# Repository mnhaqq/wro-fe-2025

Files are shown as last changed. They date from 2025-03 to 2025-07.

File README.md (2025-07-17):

# Lonely At The Top
This is the official repository of team LONELY AT THE TOP for the World Robot Olympiad Future Engineers category. This repository contains everything related to the development of the robot. And this README contains the official documentation of the team.

# 📜 Repository Overview

Welcome to our robotics project repository! Here's a breakdown of the contents:

- **`schemes/`**  
  Contains the circuit diagrams used in our robot.

- **`models/`**  
  Includes all the 3D printed parts of the robot that will be taken to the international competition.

- **`src/`**  
  All source code for both challenges — with and without obstacles.

- **`t-photos/`**  
  Photos of the team, including one formal shot and one funny shot.

- **`v-photos/`**  
  Photos of the robot from every angle, including previous versions.

- **`video/`**  
  Contains videos where you can see our robot in action, completing both challenges.

- **`README.md`**  
  Our complete development journey! Here we explain every aspect of building the robot — from design to implementation.

# Components
A list of all the electrical components in the robot.
<table>
  <tr>
    <td><strong>Step Down Module</strong></td>
    <td><strong>Raspberry Pi 5</strong></td>
    <td><strong>Raspberry Pi 12MP Camera Module 3</strong></td>
  </tr>
  <tr>
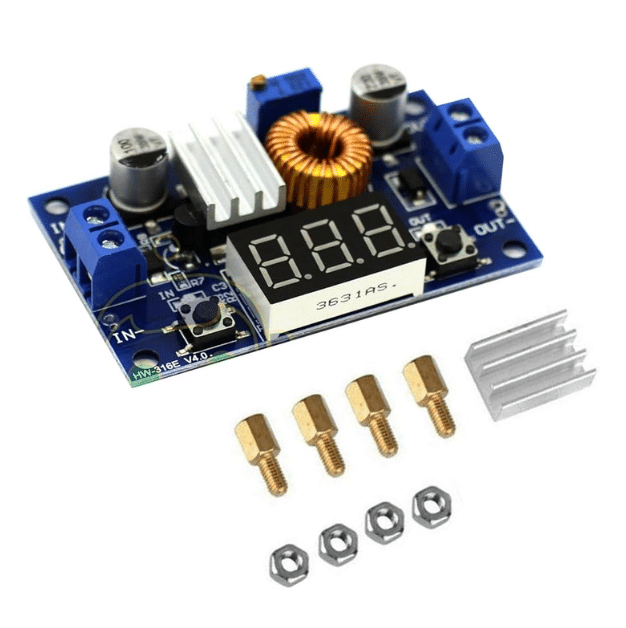
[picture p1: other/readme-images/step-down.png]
    <td></td>
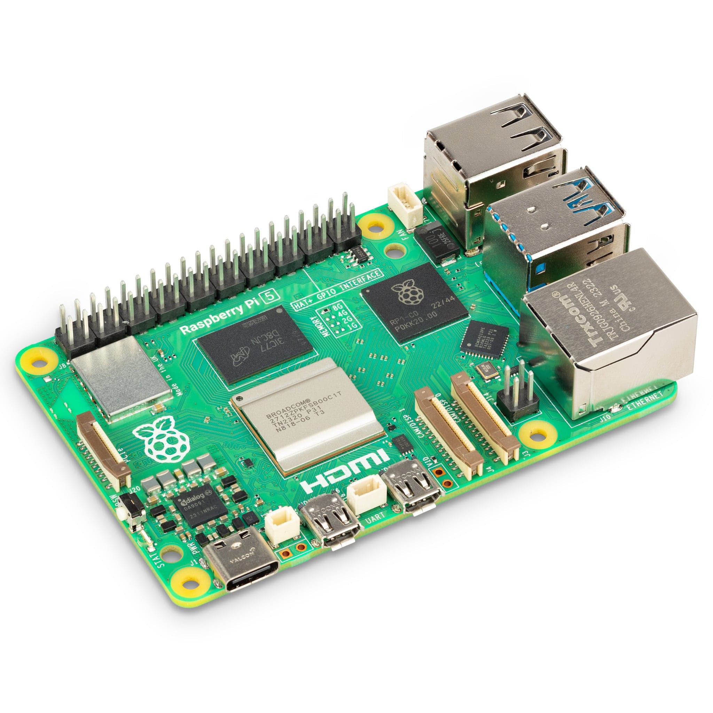
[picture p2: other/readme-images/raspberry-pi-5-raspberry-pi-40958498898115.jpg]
    <td></td>
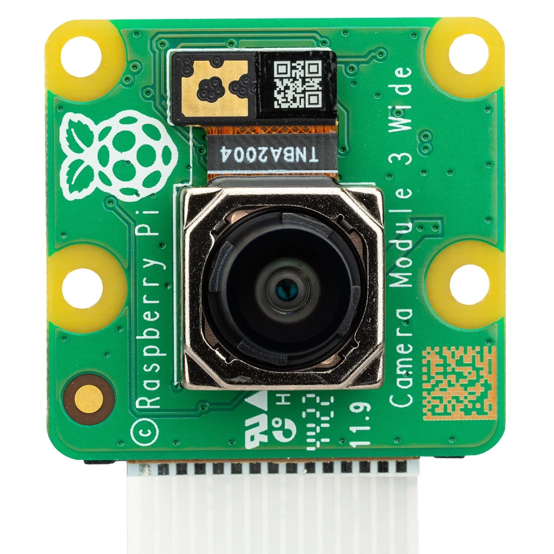
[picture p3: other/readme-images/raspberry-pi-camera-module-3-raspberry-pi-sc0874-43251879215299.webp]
    <td></td>
  </tr>
  <tr>
    <td><strong>Arduino Nano</strong></td>
    <td><strong>10k ohm resistor</strong></td>
    <td><strong>Push Button</strong></td>
  </tr>
  <tr>
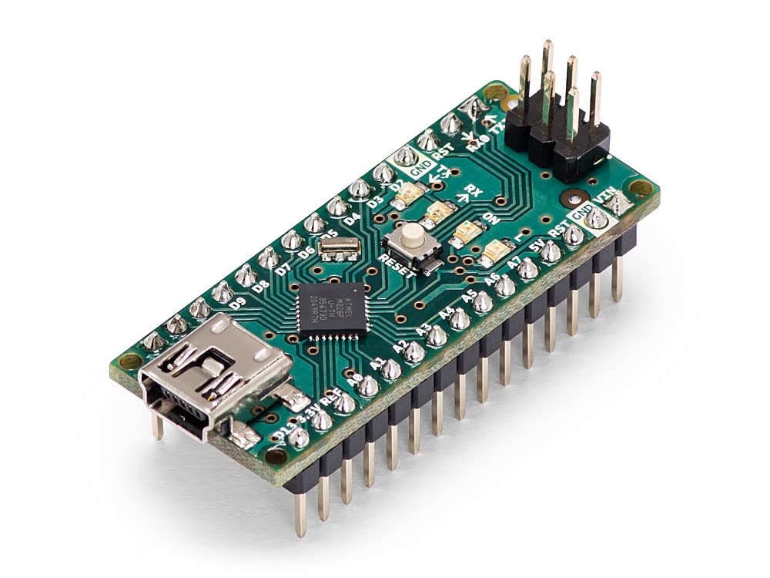
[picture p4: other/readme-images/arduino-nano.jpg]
    <td></td>
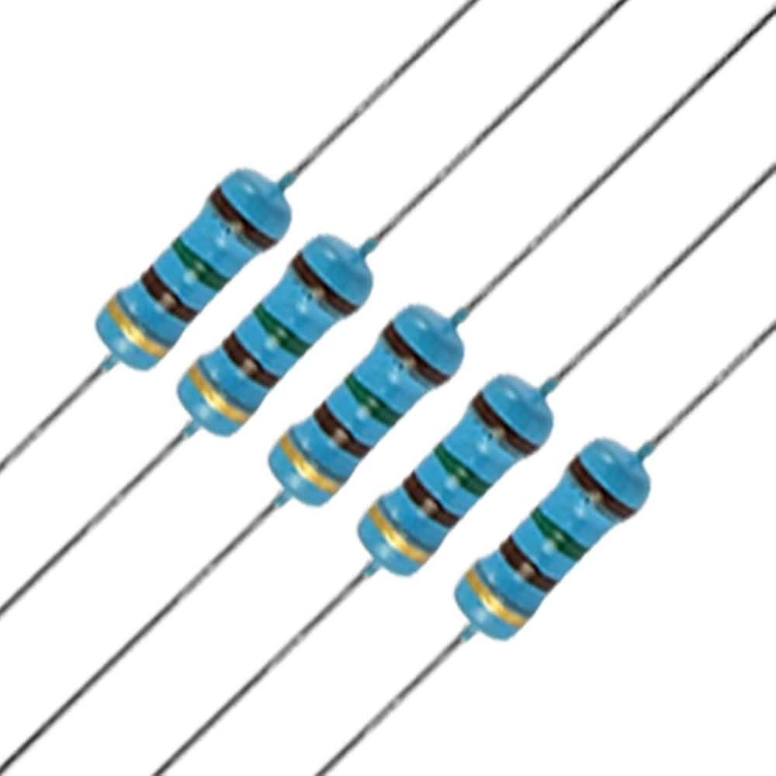
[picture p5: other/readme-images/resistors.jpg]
    <td></td>
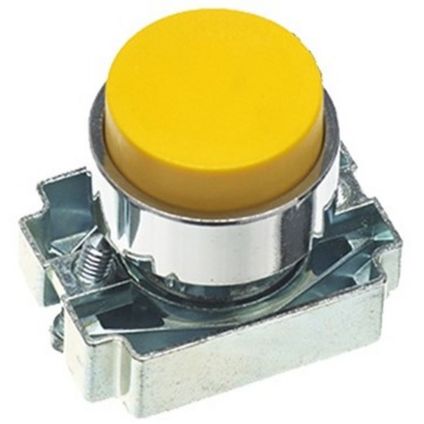
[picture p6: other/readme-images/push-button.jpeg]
    <td></td>
  </tr>
  <tr>
    <td><strong>USB cable A to USB Mini B</strong></td>
    <td><strong>4x 18650 Batteries</strong></td>
    <td><strong>Jumper Wires</strong></td>
  </tr>
  <tr>
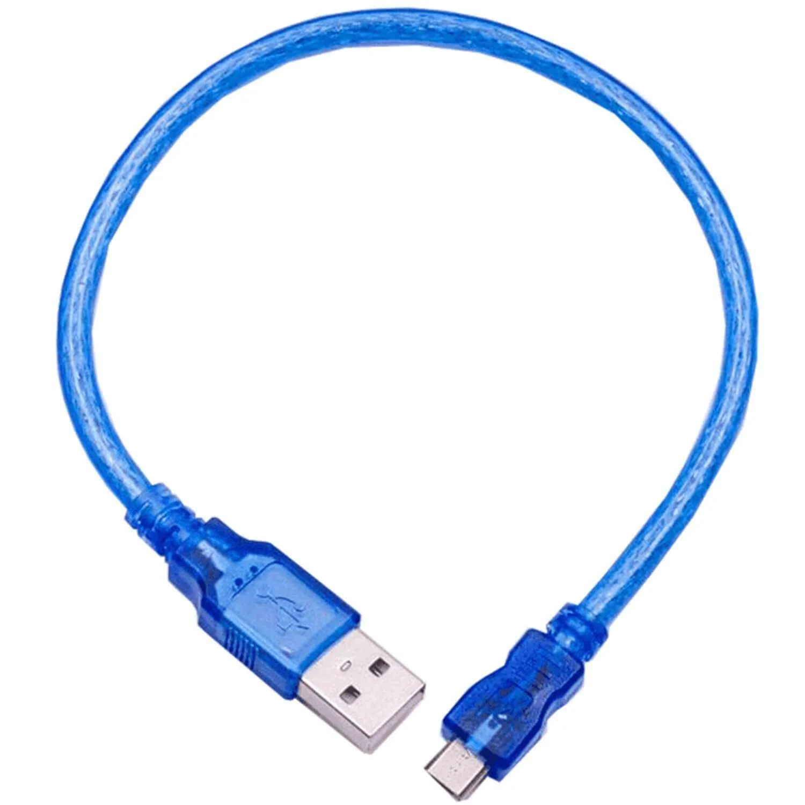
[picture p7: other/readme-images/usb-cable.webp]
    <td></td>
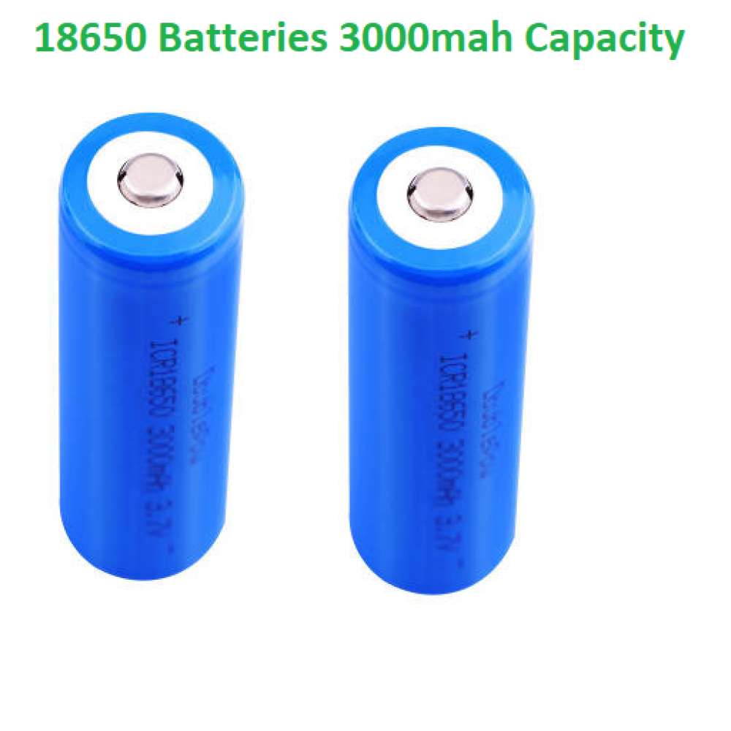
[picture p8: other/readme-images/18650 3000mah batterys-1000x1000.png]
    <td></td>
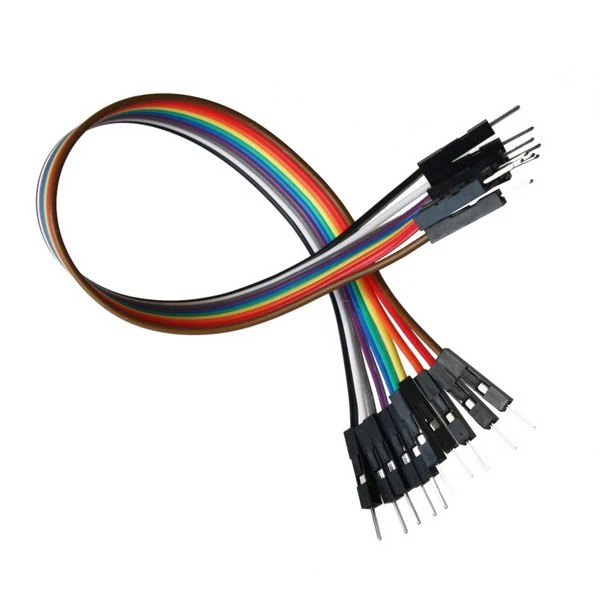
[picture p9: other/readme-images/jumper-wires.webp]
    <td></td>
  </tr>
  <tr>
    <td><strong>Raspberry Pi FPC Camera Cable</strong></td>
    <td><strong>LaTrax Rally 75054</strong></td>
    <td></td>
  </tr>
  <tr>
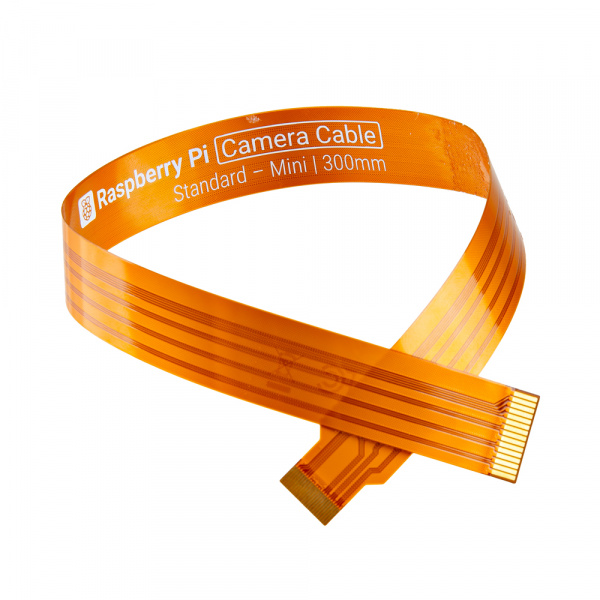
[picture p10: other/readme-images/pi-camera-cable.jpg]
    <td></td>
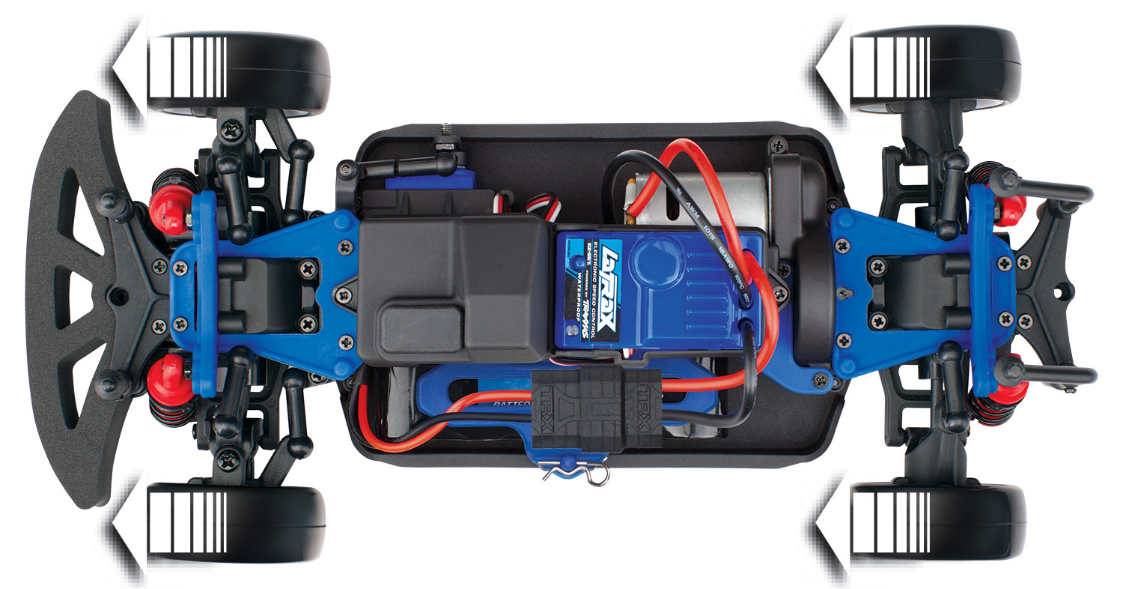
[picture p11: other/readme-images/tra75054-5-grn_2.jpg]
    <td></td>
    <td></td>
  </tr>
</table>

Below we show how we connect all these componenents
## 🧩 Use of Each Component

### 🔌 DC-DC XL4015 Adjustable Step-down Module (5A 75W with Digital Voltmeter)
This power module is used to **step down the voltage** from our 2s2p 18650 battery pack (8.4V when fully charged) to a stable **5.2V**, which is ideal for powering the **Raspberry Pi 5**.  
The built-in digital display helps us monitor the output voltage easily and adjust it precisely, ensuring the Raspberry Pi receives clean and safe power throughout operation.

---

### 🧠 Raspberry Pi 5
This serves as the **main processing unit or brain** of our robot. It handles:
- Real-time image processing from the camera module  
- Sensor data interpretation  
- Pathfinding algorithms and decision-making logic  
- Communication with the Arduino Nano  

We chose the Raspberry Pi 5 due to its powerful processor, increased RAM, and GPIO compatibility, making it perfect for compute-heavy robotics tasks.

---

### 📷 Raspberry Pi 12MP Camera Module 3
This camera captures **high-resolution images** of the game field, which are then processed by the Raspberry Pi for tasks such as:
- Line and object detection  
- Path planning  
- Visual-based decisions  

Its high quality and native Pi compatibility make it ideal for real-time computer vision applications.

---

### 🧰 Arduino Nano
The **Arduino Nano** is used as a dedicated microcontroller to:
- Interface with motor drivers  
- Control the steering servo and drive motors  
- Execute low-level, timing-critical control tasks  

This division of labor makes the control system more efficient and responsive.

---

### 📏 10kΩ Resistor
We use this as a **pull-down resistor** in our push button circuit to ensure that the GPIO pin connected to the button reads a stable LOW state when the button is not pressed, preventing **false signals**.

---

### 🔘 Push Button
A simple button used to **start or stop the robot's program**.  
It gives us manual control over the code execution without needing remote access or a keyboard.

---

### 🔋 18650 Lithium-ion Batteries (2s2p Configuration)
We wired four 18650 cells in a **2-series 2-parallel** configuration to:
- Get a nominal voltage of 7.4V (8.4V when fully charged)  
- Double the capacity and current output  

This ensures sufficient runtime and power delivery for the Raspberry Pi and motors.

---

### 🧵 Jumper Wires
Used to connect various components such as:
- Sensors to the Raspberry Pi  
- GPIO pins to the button and ultrasonic module  

They offer flexibility and are great for testing and prototyping.

---

### 🔌 USB Cable A to Mini B
This cable connects the **Raspberry Pi to the Arduino Nano**, enabling:
- Power supply to the Arduino  
- Serial communication for sending control commands  

Essential for integrating the two microcontrollers.

---

### 🚗 LaTrax Rally 75054 Chassis
This is a **commercial RC car chassis** we used as the robot's base. It provides:
- A strong and stable platform  
- Built-in drivetrain and suspension  
- Easy mounting for electronics and sensors  

It reduced the time spent on mechanical design and improved mobility and reliability.

---

### 🎥 Raspberry Pi FPC Camera Cable (Standard-Mini)
This flexible flat ribbon cable connects the **Camera Module 3** to the Raspberry Pi.  
The mini connector fits perfectly with our camera, and the cable length allows us to position the camera optimally for capturing the game field.

---

# Circuit Diagram
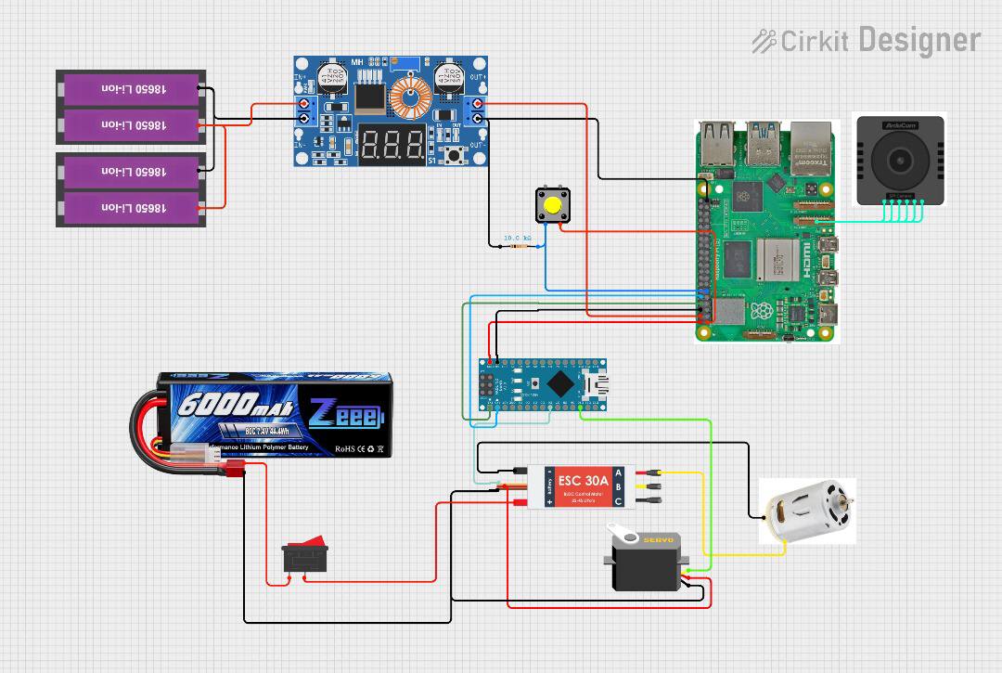
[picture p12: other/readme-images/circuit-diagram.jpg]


This circuit diagram represents the core electronic system of our robot, powered by two distinct battery packs and controlled using both an **Arduino Nano** and a **Raspberry Pi 5**. Each component is strategically connected to fulfill its specific function in the robot's operation.

### ⚙️ Power Supply and Regulation

- The system uses two battery packs:
  - A **2S2P 18650 Li-ion battery pack** to power the Raspberry Pi through a **DC-DC XL4015 step-down converter**, which regulates the voltage from 8.4V down to 5.2V to ensure safe operation of the Pi.
  - A **6000mAh 7.4V LiPo battery** is dedicated to powering the **DC motor** via an **ESC (Electronic Speed Controller)**, providing the high current required for reliable movement and acceleration.

### 🧠 Microcontroller & Microprocessor

- The **Raspberry Pi 5** serves as the central processing unit of the robot. It:
  - Processes data from the **Raspberry Pi Camera Module**
  - Sends movement instructions to the **Arduino Nano**
  - Interfaces with input components like the **push button** through GPIO pins

- The **Arduino Nano** is responsible for:
  - Receiving control commands from the Raspberry Pi
  - Driving the **servo motor** for steering
  - Sending PWM signals to the **ESC** to control the DC motor
  - Handling low-level real-time tasks for precise control

### 📷 Camera Integration

A **12MP Camera Module 3** is connected to the Raspberry Pi using a **FPC ribbon cable**. This camera captures visual data from the field for image processing tasks such as:
- Line tracking
- Object detection
- Lane following and obstacle avoidance

This enables the robot to make autonomous navigation decisions based on what it "sees."

### 🔁 Actuation

- A **DC motor**, connected through an **ESC**, provides torque and speed for forward and backward movement.
- A **servo motor** controls the steering mechanism of the chassis, allowing the robot to make turns with precision.

### 🎮 Input and Control

- A **push button** is connected to the Raspberry Pi via GPIO pins and a **10kΩ resistor** (as a pull-down resistor) to prevent floating values. This button is used to **start or stop** the program execution manually.
- **Jumper wires (UTP)** are used to make precise connections between components like the sensors, Arduino, and Raspberry Pi, ensuring signal integrity and clean communication.

---

### ✅ Summary

This modular design ensures:
- **Separation of logic and power domains**, preventing electrical noise or surges from affecting control logic
- **Efficient power delivery** to both the Raspberry Pi and motors
- **Clear division of responsibilities** between the Raspberry Pi (for high-level processing) and Arduino (for motor control)
- **Scalability**, allowing us to easily modify or extend the system for future challenges

The diagram illustrates a robust and well-integrated control system suitable for real-world robotic competitions, ensuring stability, performance, and flexibility in operation.

# 3D Parts
| Part | Description |
|---|---|
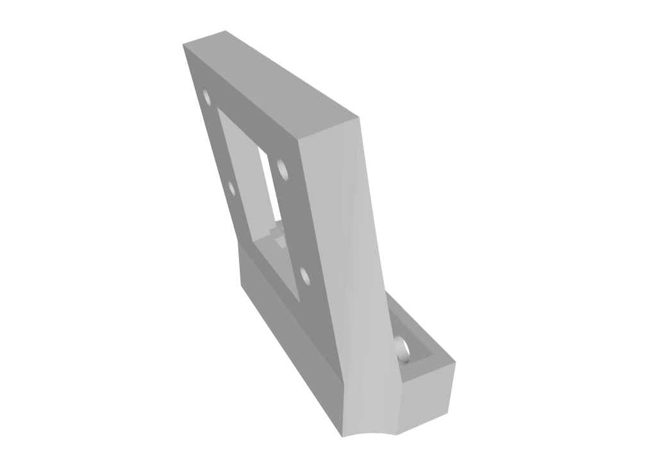
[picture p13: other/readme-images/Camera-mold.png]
|  | This 3D-printed component serves as a protective and structural housing for the camera, referred to as the camera mold. It is angled at approximately 170 degrees to optimize the camera's field of view, enabling better visibility of the game field during operation. |
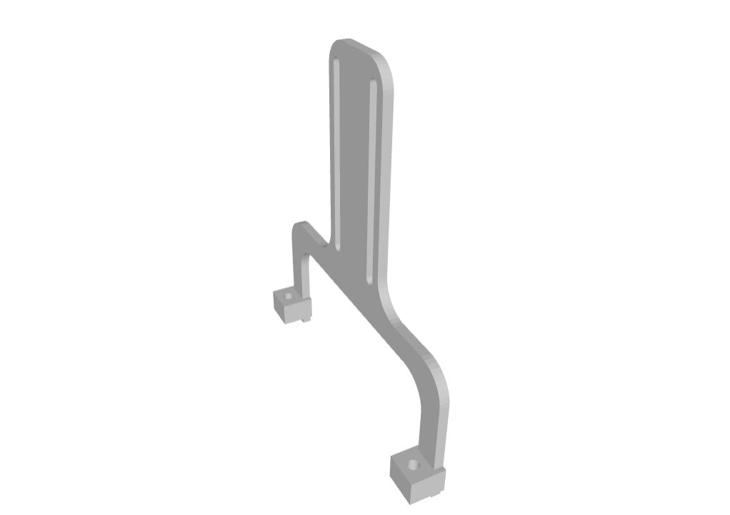
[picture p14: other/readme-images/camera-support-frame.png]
|  | This is the camera support frame, designed to pair with the camera mold to ensure stable and accurate camera positioning. Its adjustable height mechanism allows fine-tuning of the camera's elevation to achieve the desired field of view, enhancing visibility of the game field. |
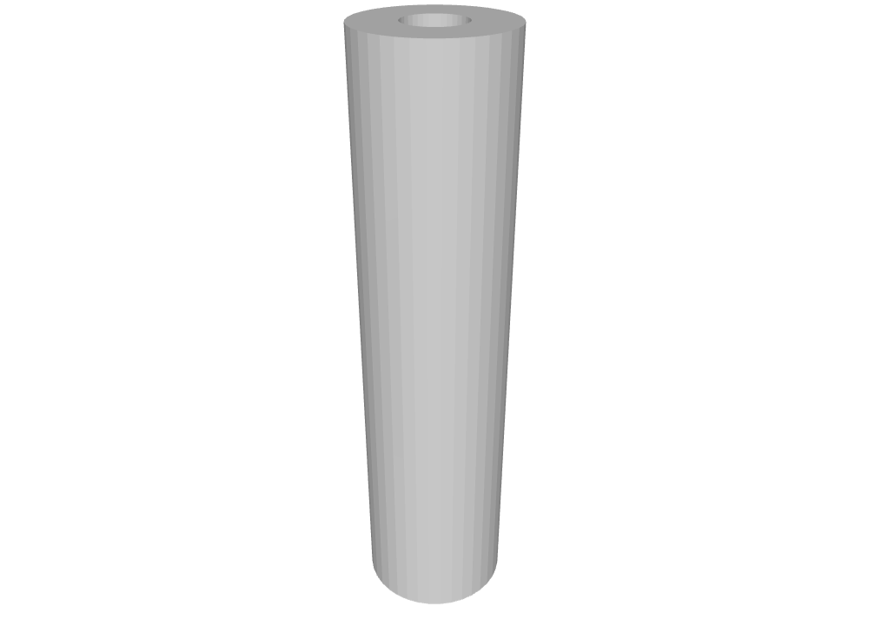
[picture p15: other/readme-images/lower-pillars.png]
|  | These pillars serve as the structural supports for the robot, holding up each deck and ensuring overall stability. Designed to bear the weight of the stacked components, the eight pillars also provide connection points that keep the entire robot assembly securely integrated |
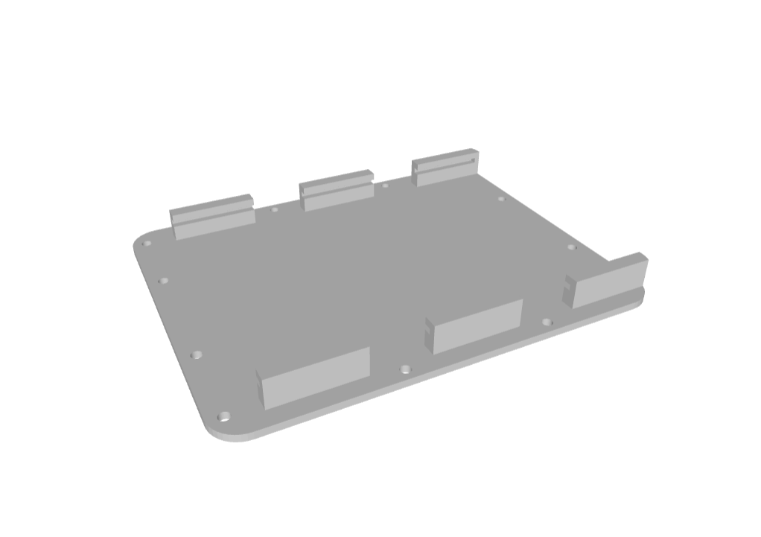
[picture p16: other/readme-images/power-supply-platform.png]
|  | This is the second deck (counting from the top), designed to hold the step-down power module and the batteries that supply power to the Raspberry Pi 5. It provides a stable platform for power distribution components and ensures efficient use of vertical space in the robot’s design. |
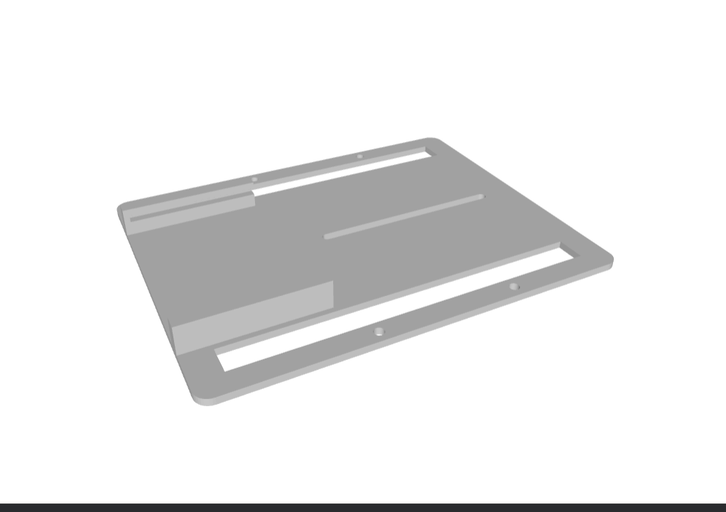
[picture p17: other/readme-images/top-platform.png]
|  | This is the first deck (topmost level), which houses the Raspberry Pi 5, Arduino Nano, and a control button. It also interfaces with the camera support frame, featuring a sliding mechanism that allows the frame to be adjusted forward or backward as needed to optimize the camera’s positioning. |
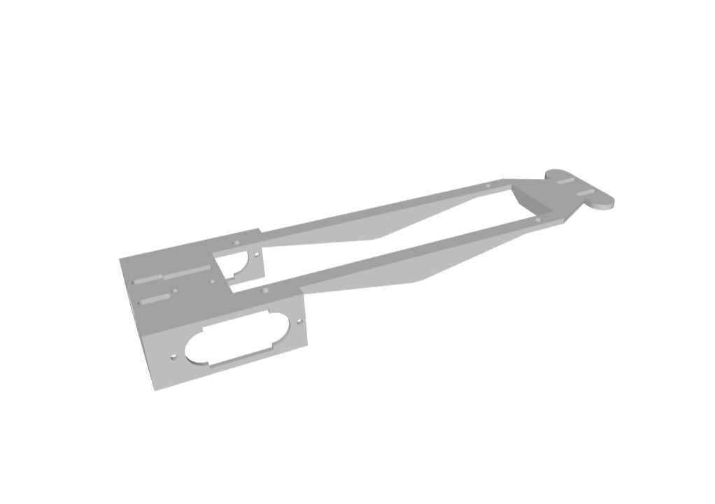
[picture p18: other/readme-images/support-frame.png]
|  | Serve as the foundation for the robot's structure. Provides support for all other printed components and form the critical connection between the RC chassis and the custom 3D-printed assemblies, ensuring a stable and integrated build.  |
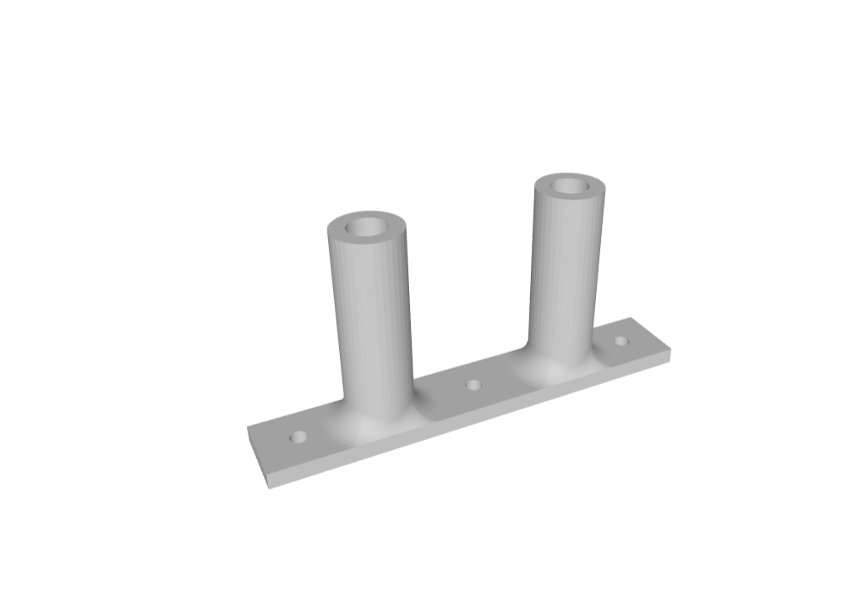
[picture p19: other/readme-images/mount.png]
|  | Combined with the support frame above to perform it's function. There's two of this part |

# Code and Programming Overview

The codebase is divided into two main components, each located in separate folders:

## PiArduinoInterface

This folder contains the Arduino code responsible for low-level control of the vehicle. It manages the **steering servo** and **driving motor**, and receives commands from the Raspberry Pi over a serial interface.

### File Overview

#### `PiArduinoInterface.ino`
The main entry point of the Arduino program:
- Sets up serial communication and initializes hardware components (servos and motors).
- Continuously reads and parses commands sent from the Raspberry Pi.
- Executes commands such as setting motor speed or adjusting servo angles.
- Includes an **auto-stop safety feature** that stops the motor if no command is received within a set interval.

#### `commands.h`
Defines the set of valid single-character serial commands used by the Raspberry Pi to control the Arduino:
- Examples include:  
  - `'s'` – Set servo position  
  - `'m'` – Set motor speed  
  - `'d'` – Digital read  
  - `'a'` – Analog read  

These commands are parsed and executed in `PiArduinoInterface.ino`.

#### `servos.h`
Declares the `SweepServo` class and configuration settings for the servos:
- Controls how fast the servo sweeps to its target position.
- Stores pin assignments and initial angles.
- Declares a global array `servos[]` for managing multiple servos.

#### `servos.ino`
Implements the `SweepServo` class:
- Smoothly moves a servo to a target position one degree at a time.
- Supports adjustable speed via a delay between steps.
- Useful for precise or slow movements, such as robotic arms or steering mechanisms.

#### `motor_driver.h`
Contains motor control settings:
- Specifies the motor control pin (default: pin 3) used for the ESC (Electronic Speed Controller).
- Declares functions for initializing the motor and setting its speed.

#### `motor_driver.ino`
Implements the motor driver functions:
- Uses the `Servo` library to control an ESC-based brushed or brushless motor.
- Supports setting motor speed via PWM signals.
- Provides an `initMotorController()` function to safely initialize the ESC.

---

# MainCode
---
This folder contains the main logic and it controls the arduino which in turn controls motors

## `start.py` — Script Launcher via Physical Button

This script enables hardware-based control of another Python script (`open.py`) using a physical push button connected to a Raspberry Pi's GPIO pin. Pressing the button starts the `open.py` script, and pressing it again stops the script.

---

### Features

* Uses GPIO interrupts to detect button press.
* Launches `open.py` or `obstacle` using `subprocess.Popen`.
* Pressing the button again terminates the script gracefully.
* Cleanly shuts down on keyboard interrupt (`Ctrl+C`).

---

### Code Breakdown

```python
import RPi.GPIO as GPIO
import subprocess
import time
import os
import signal
```

Imports all necessary libraries:

* `RPi.GPIO` for interacting with GPIO pins.
* `subprocess` for running external scripts.
* `os` and `signal` for process control.

---

```python
BUTTON_PIN = 17
GPIO.setmode(GPIO.BCM)
GPIO.setup(BUTTON_PIN, GPIO.IN, pull_up_down=GPIO.PUD_DOWN)
```

* Sets **GPIO17** as input.
* Configures it with a **pull-down resistor** to detect rising edges (button press).

---

```python
process = None
```

* Stores a reference to the running process so it can be terminated later.

---

```python
def toggle_executable(channel):
    global process
    if process is None:
        print("Button pressed! Starting script...")
        process = subprocess.Popen(
            ['python3', 'open.py'],
            cwd='/home/pi/Documents/wro-fe-2025/src/MainCode/'
        )
    else:
        print("Button pressed! Stopping script...")
        try:
            os.kill(process.pid, signal.SIGTERM)
        except Exception as e:
            print(f"Error stopping script: {e}")
        process = None
```

This **callback function** is triggered when the button is pressed:

* If no script is running, it launches `open.py`.
* If a script is already running, it stops it using `SIGTERM`.

---

```python
GPIO.add_event_detect(BUTTON_PIN, GPIO.RISING, callback=toggle_executable, bouncetime=300)
```

Registers an **interrupt** on the button pin for **rising edge detection**.

* `bouncetime=300` helps to debounce the button (ignores multiple presses within 300ms).

---

```python
try:
    print("Waiting for button press to toggle script...")
    while True:
        time.sleep(0.1)
except KeyboardInterrupt:
    pass
finally:
    GPIO.cleanup()
    if process:
        os.kill(process.pid, signal.SIGTERM)
```

Main loop waits for button events.

* Gracefully cleans up GPIO and stops the running process on `Ctrl+C`.

---

## `ArduinoComms.py` — Arduino Serial Communication Handler

This module provides a Python class for communicating with an Arduino over a serial connection using the `pyserial` library. It supports sending drive and steering commands, as well as handling connection setup, teardown, and message formatting.

---

### Features

* Connect to an Arduino over a serial port.
* Automatically validates and converts baud rates.
* Send and receive messages over serial.
* Built-in functions to control drive and steering motor values.

---

### Code Breakdown

#### Baud Rate Validation

```python
def convert_baud_rate(baud_rate):
    supported_baud_rates = [
        1200, 1800, 2400, 4800, 9600,
        19200, 38400, 57600, 115200, 230400
    ]
    if baud_rate in supported_baud_rates:
        return baud_rate
    else:
        print(f"Error! Baud rate {baud_rate} not supported! Defaulting to 57600")
        return 57600
```

* Ensures only supported baud rates are used.
* Falls back to a default value of **57600** if an unsupported rate is provided.

---

### `ArduinoComms` Class

#### Connect to Arduino

```python
comms = ArduinoComms()
comms.connect(serial_device='/dev/ttyUSB0', baud_rate=57600, timeout_ms=1000)
```

* `serial_device`: Serial port connected to the Arduino (e.g. `/dev/ttyUSB0` on Linux, `COM3` on Windows).
* `baud_rate`: Must be one of the supported baud rates.
* `timeout_ms`: Timeout for reading serial data, in milliseconds.

---

#### Disconnect

```python
comms.disconnect()
```

* Closes the serial connection if it's open.

---

#### Check Connection Status

```python
if comms.connected():
    print("Arduino is connected.")
```

* Returns `True` if the serial port is open.

---

#### Send Messages

```python
response = comms.send_msg("ping\r", print_output=True)
```

* Sends a message string (terminated by `\r`).
* Optionally prints both the sent and received message.
* Returns the decoded response string.

---

#### Send Empty Message

```python
comms.send_empty_msg()
```

* Sends an empty carriage return to "ping" the Arduino or reset the line.

---

#### Set Drive Motor Value

```python
comms.set_drive_motor_value(100)
```

* Sends a command in the format: `o <value>\r`
* Used to control the drive motor speed.

---

#### Set Steering Motor Value

```python
comms.set_steering_motor_value(-30)
```

* Sends a command in the format: `s 0 <value>\r`
* Used to control steering angle or direction.

---

### Example Usage

```python
from ArduinoComms import ArduinoComms

comms = ArduinoComms()
comms.connect('/dev/ttyUSB0', 57600, 1000)

if comms.connected():
    comms.set_drive_motor_value(150)
    comms.set_steering_motor_value(-20)

comms.disconnect()
```

---

## `KeyboardControl.py` — Keyboard Interface for Arduino Motor Control

This script allows manual control of a robot’s drive and steering motors via keyboard input. It uses the `keyboard` library to detect key presses and sends commands to an Arduino over serial using the `ArduinoComms` class.

---

### Features

* Incrementally adjusts **speed** and **steering angle** based on keys pressed.
* Supports continuous key press detection with a debounce delay.
* Safe stop and reset on spacebar press.
* Graceful exit on pressing `q`.
* Automatic connection to Arduino serial port.

---

### Code Breakdown

#### Setup and Initialization

```python
class KeyboardController:
    def __init__(self):
        self.arduino = ArduinoComms()
        self.speed = 0
        self.steer = 90  # Neutral steering position
        self.last_action_time = time.time()
```

* Instantiates `ArduinoComms` for serial communication.
* Initializes speed and steering values.
* Tracks time of last input to limit update frequency.

---

#### Arduino Connection Setup

```python
def arduino_setup(self):
    try:
        self.arduino.connect('/dev/serial/by-id/usb-1a86_USB2.0-Ser_-if00-port0', 9600, 1000)
        if self.arduino.connected():
            print("Connected to Arduino.")
        else:
            print("Failed to connect.")
    except Exception as e:
        print(f"Error: {e}")
```

* Connects to Arduino at the specified serial port and baud rate.
* Handles exceptions and reports connection status.

---

#### Speed and Steering Controls

```python
def set_speed(self, direction):
    if direction:
        self.speed += 10
    else:
        self.speed -= 10
    self.speed = max(min(self.speed, 500), -500)
    if self.arduino.connected():
        self.arduino.set_drive_motor_value(self.speed)
```

* Adjusts speed by ±10 units per key press.
* Limits speed between -500 and 500.
* Sends updated speed to Arduino.

```python
def set_steer(self, direction):
    if direction:
        self.steer += 5
    else:
        self.steer -= 5
    self.steer = max(min(self.steer, 135), 45)
    if self.arduino.connected():
        self.arduino.set_steering_motor_value(self.steer)
```

* Adjusts steering angle by ±5 degrees per key press.
* Limits steering between 45 and 135 degrees.
* Sends updated steering value to Arduino.

---

#### Stop and Reset

```python
def stop(self):
    self.speed = 0
    self.steer = 90
    if self.arduino.connected():
        self.arduino.set_steering_motor_value(self.steer)
        self.arduino.set_drive_motor_value(self.speed)
```

* Resets speed to 0 and steering to neutral position.
* Sends stop commands to Arduino.

---

#### Main Control Loop

```python
def run(self):
    self.arduino_setup()
    try:
        while True:
            now = time.time()
            if now - self.last_action_time > 0.1:  # Debounce 100ms
                if keyboard.is_pressed('w'):
                    self.set_speed(True)
                if keyboard.is_pressed('s'):
                    self.set_speed(False)
                if keyboard.is_pressed('a'):
                    self.set_steer(True)
                if keyboard.is_pressed('d'):
                    self.set_steer(False)
                if keyboard.is_pressed('space'):
                    self.stop()
                self.last_action_time = now

            if keyboard.is_pressed('q'):
                break

            time.sleep(0.01)
    finally:
        if self.arduino.connected():
            self.arduino.disconnect()
```

* Reads keyboard input continuously.
* Updates speed and steering every 100 ms on key press.
* Stops and resets on spacebar.
* Exits on `q` and safely disconnects Arduino.

---

### Usage

Run the script with Python 3 in an environment with `keyboard` and your `ArduinoComms.py` available:

```bash
python3 keyboard_controller.py
```

Controls:

| Key | Action |
| --- | --- |
| `w` | Increase speed |
| `s` | Decrease speed |
| `a` | Steer left (increase angle)  |
| `d` | Steer right (decrease angle) |
| `space` | Stop and reset |
| `q` | Quit program |

---

###  Notes

* The script requires root or admin privileges on some OSes for `keyboard` library to detect key presses.
* Update the serial port path in `arduino_setup()` to match your system’s Arduino device.

---

## `pid.py` — PID Control Algorithm Implementation

This module implements a simple Proportional-Integral-Derivative (PID) controller class for feedback control systems, commonly used in robotics and automation.

---

### Code Breakdown

#### PID Controller Class

```python
class PIDController:
    def __init__(self, kp, ki, kd):
        self.kp = kp          # Proportional gain
        self.ki = ki          # Integral gain
        self.kd = kd          # Derivative gain
        self.prev_error = 0   # Error from previous step (for derivative term)
        self.integral = 0     # Accumulated error (for integral term)

    def compute(self, error):
        self.integral += error
        derivative = error - self.prev_error
        output = (self.kp * error) + (self.ki * self.integral) + (self.kd * derivative)
        self.prev_error = error
        return output
```

---

### Features

* Calculates the PID output given a current error value.
* Maintains internal state for integral and derivative computations.
* Simple interface: instantiate with gains and call `compute(error)` on each control cycle.

---

### Usage Example

```python
pid = PIDController(kp=1.2, ki=0.01, kd=0.05)

while True:
    error = desired_value - measured_value
    control_signal = pid.compute(error)
    # Use control_signal to drive actuators
```

---

### ⚙️ Notes

* Make sure to call `compute` regularly with the latest error measurement.
* Gains (`kp`, `ki`, `kd`) should be tuned for your specific system for stable control.

---

## `utils.py` — Image Processing for Color-Based Object Detection

This module provides utility functions to detect colored objects in specific Regions of Interest (ROIs) within images, using OpenCV and LAB color space thresholds.

---

### Functions Overview

---

#### `display_roi(img, ROIs, color)`

Draws bounding boxes around specified ROIs on the given image.

```python
def display_roi(img, ROIs, color):
    for ROI in ROIs: 
        img = cv2.line(img, (ROI[0], ROI[1]), (ROI[2], ROI[1]), color, 4)
        img = cv2.line(img, (ROI[0], ROI[1]), (ROI[0], ROI[3]), color, 4)
        img = cv2.line(img, (ROI[2], ROI[3]), (ROI[2], ROI[1]), color, 4)
        img = cv2.line(img, (ROI[2], ROI[3]), (ROI[0], ROI[3]), color, 4)
    
    return img
```

* **Parameters:**

  * `img` — The image to draw on.
  * `ROIs` — List of tuples defining rectangular regions `(x1, y1, x2, y2)`.
  * `color` — Color for the ROI lines (BGR tuple).
* **Returns:** Image with ROI rectangles drawn.

---

#### `find_contours(img_lab, lab_range, ROI)`

Segments the LAB image within a ROI using color thresholds, applies morphological operations, and finds contours of the detected regions.

```python
def find_contours(img_lab, lab_range, ROI):
    img_segmented = img_lab[ROI[1]:ROI[3], ROI[0]:ROI[2]]
    lower_mask = np.array(lab_range[0])
    upper_mask = np.array(lab_range[1])
    mask = cv2.inRange(img_segmented, lower_mask, upper_mask)
    kernel = np.ones((5, 5), np.uint8)
    eMask = cv2.erode(mask, kernel, iterations=1)
    dMask = cv2.dilate(eMask, kernel, iterations=1)
    contours = cv2.findContours(dMask, cv2.RETR_EXTERNAL, cv2.CHAIN_APPROX_SIMPLE)[-2]
    return contours
```

* **Parameters:**

  * `img_lab` — LAB color space image.
  * `lab_range` — Tuple of lower and upper LAB thresholds.
  * `ROI` — Region of interest as `(x1, y1, x2, y2)`.
* **Returns:** List of contours found in the segmented ROI.

---

#### `max_contour(contours, ROI)`

Finds the largest contour by area that exceeds a minimum size threshold and returns its properties.

```python
def max_contour(contours, ROI): 
    maxArea = 0
    maxY = 0
    maxX = 0
    mCnt = 0
    
    for cnt in contours:
        area = cv2.contourArea(cnt)
        if area > 100: 
            approx = cv2.approxPolyDP(cnt, 0.01*cv2.arcLength(cnt,True), True)
            x,y,w,h = cv2.boundingRect(approx)
            x += ROI[0] + w // 2
            y += ROI[1] + h
            if area > maxArea:
                maxArea = area
                maxY = y
                maxX = x
                mCnt = cnt
    return [maxArea, maxX, maxY, mCnt]
```

* **Parameters:**

  * `contours` — List of contours.
  * `ROI` — Region of interest as `(x1, y1, x2, y2)`.
* **Returns:** List `[maxArea, maxX, maxY, maxContour]` representing the largest contour’s area, centroid X, centroid Y, and contour points.

---

#### `display_variables(variables)`

Prints multiple variable name-value pairs in the terminal and overwrites the previous output for real-time updates.

```python
def display_variables(variables):
    names = list(variables.keys())
    for i in range(len(names)):
        name = names[i]
        value = variables[name]
        print(f"{name}: {value}", end="\r\n")
    print("\033[F" * len(names), end="")
```

* **Parameters:**

  * `variables` — Dictionary of `{variable_name: value}` pairs.
* **Purpose:** Useful for real-time CLI display of tracking or sensor variables.

---

#### `pOverlap(img_lab, ROI, add=False)`

Detects contours of overlapping black and magenta regions within the ROI using LAB thresholding and optional mask combination.

```python
def pOverlap(img_lab, ROI, add=False):
    lower_mask = np.array(rBlack[0])
    upper_mask = np.array(rBlack[1])
    mask = cv2.inRange(img_lab[ROI[1]:ROI[3], ROI[0]:ROI[2]], lower_mask, upper_mask)

    lower_mask2 = np.array(rMagenta[0])
    upper_mask2 = np.array(rMagenta[1])
    mask2 = cv2.inRange(img_lab[ROI[1]:ROI[3], ROI[0]:ROI[2]], lower_mask2, upper_mask2)

    if not add: 
        mask = cv2.subtract(mask, cv2.bitwise_and(mask, mask2))
    else:
        mask = cv2.add(mask, mask2)

    kernel = np.ones((5, 5), np.uint8)
    eMask = cv2.erode(mask, kernel, iterations=1)
    contours = cv2.findContours(eMask, cv2.RETR_EXTERNAL, cv2.CHAIN_APPROX_SIMPLE)[-2]
    return contours
```

* **Parameters:**

  * `img_lab` — LAB color space image.
  * `ROI` — Region of interest.
  * `add` — If True, adds masks; if False, subtracts overlapping parts.
* **Returns:** List of contours found in combined masks.

---

# `open.py` - Autonomous Driving with Picamera2 and Arduino

This script implements an autonomous line following and turning system using the Raspberry Pi camera (Picamera2), Arduino motor control, and PID steering adjustments based on color detection.

---

## Overview

The program captures images from the PiCamera2, processes them in the LAB color space to detect colored regions in predefined Regions of Interest (ROIs), and computes steering angles using a PID controller. It drives motors through an Arduino based on detected path lines and turn signals.

---

## Key Features

* **PiCamera2 Setup:** Automatically selects suitable sensor modes and configures the camera.
* **Color Segmentation:** Uses LAB thresholds to detect black lines (path) and orange/blue markers (turn signals).
* **PID Steering Control:** Smooth steering adjustment based on difference in detected left and right line areas.
* **Turn Detection:** Detects turns and applies angle constraints with cooldowns to avoid repeated turn counting.
* **Arduino Communication:** Controls drive motor speed and steering angle via serial commands.
* **Debug Mode:** Visualizes ROIs, contours, and prints variable states in real-time.

---

## Usage

1. Connect the Raspberry Pi camera and Arduino controller.
2. Confirm the Arduino serial port in the script (`/dev/serial/by-id/usb-1a86_USB2.0-Ser_-if00-port0`).
3. Run the script:

```bash
python open.py
```

4. Press `q` during debug mode to quit the program.

---

## Code Snippets

### PiCamera2 Initialization and Configuration

```python
picam2 = Picamera2()
sensor_modes = picam2.sensor_modes
selected_mode = None
for mode in sensor_modes:
    if mode['size'] in [(2304, 1296), (1920, 1080), (1280, 720)]:
        selected_mode = mode
        break
if selected_mode is None:
    selected_mode = sensor_modes[0]

config = picam2.create_preview_configuration(
    main={"format": "RGB888", "size": (1280, 720)},
    sensor={"output_size": selected_mode['size'], "bit_depth": selected_mode['bit_depth']}
)

picam2.configure(config)
picam2.start()
time.sleep(1)
```

---

### Defining Regions of Interest (ROIs)

```python
# Left, Right, and Center ROIs for line and turn detection
ROI1 = [10, 420, 200, 500]    # Left
ROI2 = [1080, 420, 1270, 500] # Right
ROI3 = [540, 420, 740, 500]   # Center
```

---

### PID Controller Usage for Steering

```python
pid = PIDController(kp=0.001, ki=0, kd=0.0009)
error = rightArea - leftArea
angle = int(max(90 + pid.compute(error), 0))
```

---

### Detecting Turns and Adjusting Steering

```python
if leftArea <= turnThresh and not rTurn:
    lTurn = True
elif rightArea <= turnThresh and not lTurn:
    rTurn = True

if lTurn:
    angle = min(max(angle, sharpLeft), maxLeft)
elif rTurn:
    angle = max(min(angle, sharpRight), maxRight)
```

---

### Sending Commands to Arduino

```python
arduino.set_drive_motor_value(speed)
arduino.set_steering_motor_value(angle)
```

---

### Debug Visualization and Variables Display

```python
img = display_roi(img, [ROI1, ROI2, ROI3], (255, 204, 0))
cv2.imshow("finalColor", img)

variables = {
    "left wall area": leftArea,
    "right wall area": rightArea,
    "left turn": lTurn,
    "right turn": rTurn,
    "# turns": t,
    "lDetected": lDetected
}

display_variables(variables)

if cv2.waitKey(1) == ord('q'):
    arduino.set_drive_motor_value(0)
    break
```

---

## Parameters to Tune

* `kp`, `kd`: PID controller gains for proportional and derivative control.
* `speed`: Motor speed value.
* `turnThresh`: Threshold for detecting turn conditions.
* `exitThresh`: Threshold for detecting turn completion.
* `turn_cooldown`: Time delay to avoid counting turns multiple times.

---

# `obstacle.py` - Autonomous Lane Following and Obstacle Avoidance with PiCamera2 and Arduino

This Python script enables autonomous navigation using the Raspberry Pi Camera (Picamera2) and an Arduino for motor control. It detects colored markers and lines on the floor to steer a robot along a track, including turn detection and pillar avoidance.

---

## Features

* Captures real-time images with Picamera2.
* Detects black path lines and colored turn signals (orange, blue).
* Detects red and green pillars to trigger specific turn maneuvers.
* Uses a PID controller for smooth steering adjustments.
* Sends speed and steering commands to Arduino via serial.
* Visual debug mode with real-time contour visualization and variable display.
* Turn counting with cooldown to avoid repeated triggers.

---

## Setup Highlights

### Camera Initialization and Configuration

```python
picam2 = Picamera2()
sensor_modes = picam2.sensor_modes
selected_mode = None
for mode in sensor_modes:
    if mode['size'] in [(2304, 1296), (1920, 1080), (1280, 720)]:
        selected_mode = mode
        break
if selected_mode is None:
    selected_mode = sensor_modes[0]

config = picam2.create_preview_configuration(
    main={"format": "RGB888", "size": (1280, 720)},
    sensor={"output_size": selected_mode['size'], "bit_depth": selected_mode['bit_depth']}
)

picam2.configure(config)
picam2.start()
time.sleep(1)
```

---

### Defining Regions of Interest (ROIs) for Color Detection

```python
ROI1 = [10, 420, 200, 500]       # Left line detection region
ROI2 = [1080, 420, 1270, 500]    # Right line detection region
ROI3 = [540, 420, 740, 500]      # Center region for turn signals (orange/blue)
ROI_PILLAR = [340, 200, 940, 500] # Pillar detection region (red/green)
```

---

### PID Controller Setup for Steering

```python
kp = 0.004
kd = 0.0009
pid = PIDController(kp, 0, kd)
straightConst = 90  # Neutral steering angle
```

---

### Color Contour Detection and Steering Logic

```python
# Convert captured image to LAB color space and blur
img_lab = cv2.cvtColor(img, cv2.COLOR_BGR2Lab)
img_lab = cv2.GaussianBlur(img_lab, (7, 7), 0)

# Find contours for line and turn signal colors
cListLeft = find_contours(img_lab, rBlack, ROI1)
cListRight = find_contours(img_lab, rBlack, ROI2)
cListOrange = find_contours(img_lab, rOrange, ROI3)
cListBlue = find_contours(img_lab, rBlue, ROI3)

# Calculate max contour areas for decision making
leftArea = max_contour(cListLeft, ROI1)[0]
rightArea = max_contour(cListRight, ROI2)[0]

if max_contour(cListOrange, ROI3)[0] > 100:
    turnDir = "right"
elif max_contour(cListBlue, ROI3)[0] > 100:
    turnDir = "left"
```

---

### Detecting Pillars and Executing Turn Maneuvers

```python
cListRed = find_contours(img_lab, rRed, ROI_PILLAR)
cListGreen = find_contours(img_lab, rGreen, ROI_PILLAR)

redArea = max_contour(cListRed, ROI_PILLAR)[0]
greenArea = max_contour(cListGreen, ROI_PILLAR)[0]

if redArea > 3000:
    angle = sharpRight  # steer sharply right around red pillar
    arduino.set_steering_motor_value(angle)
    sleep(0.25)
    arduino.set_steering_motor_value(straightConst)  # straighten
elif greenArea > 900:
    angle = sharpLeft   # steer sharply left around green pillar
    arduino.set_steering_motor_value(angle)
    sleep(0.25)
    arduino.set_steering_motor_value(straightConst)
```

---

### PID-Controlled Steering and Turn Logic

```python
error = rightArea - leftArea
angle = int(max(straightConst + pid.compute(error), 0))

if leftArea <= turnThresh and not rTurn:
    lTurn = True
elif rightArea <= turnThresh and not lTurn:
    rTurn = True

if lTurn or rTurn:
    # Adjust steering for turns with angle limits
    if (rightArea > exitThresh and rTurn) or (leftArea > exitThresh and lTurn):
        lTurn = False
        rTurn = False
        pid.prev_error = 0
        # Count turns with cooldown
        current_time = time.time()
        if current_time - last_turn_time > turn_cooldown:
            t += 1
            last_turn_time = current_time
    elif lTurn:
        angle = min(max(angle, sharpLeft), maxLeft)
    elif rTurn:
        angle = max(min(angle, sharpRight), maxRight)

arduino.set_steering_motor_value(angle)
arduino.set_drive_motor_value(speed)
```

---

### Debug Mode Visuals and Exit Condition

```python
if debug:
    img = display_roi(img, [ROI1, ROI2, ROI3, ROI_PILLAR], (255, 204, 0))
    cv2.imshow("finalColor", img)

    variables = {
        "left wall area": leftArea,
        "right wall area": rightArea,
        "left turn": lTurn,
        "right turn": rTurn,
        "# turns": t,
        "lDetected": lDetected
    }

    display_variables(variables)

    if cv2.waitKey(1) == ord('q'):
        arduino.set_drive_motor_value(0)
        break
```

---

## Running the Program

Run the script on a Raspberry Pi with Picamera2 and connected Arduino:

```bash
python3 obstacle.py
```

Press **`q`** in the debug window to quit early.

---

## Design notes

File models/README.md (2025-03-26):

Models
====

This directory contains models for 3d printing

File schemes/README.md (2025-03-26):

# Electromechanical diagrams

This directory must contain one or several schematic diagrams in form of JPEG, PNG or PDF of the electromechanical components illustrating all the elements (electronic components and motors) used in the vehicle and how they connect to each other.

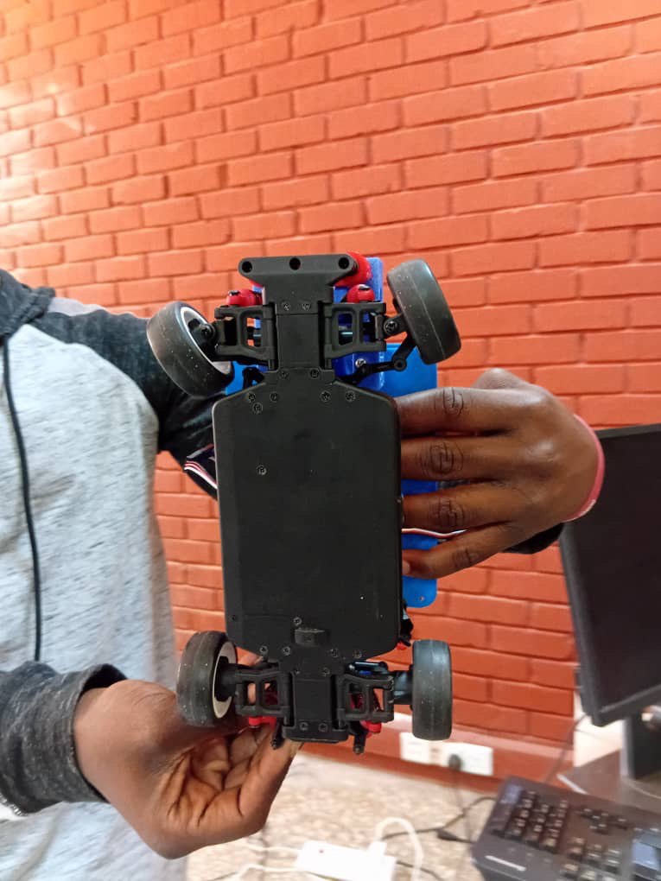
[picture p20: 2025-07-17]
v-photos/bottom.jpg

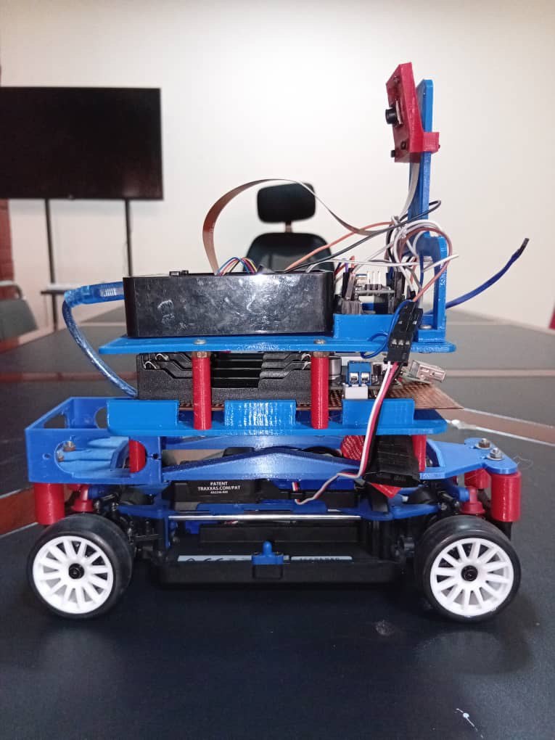
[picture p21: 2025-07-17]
v-photos/left.jpg

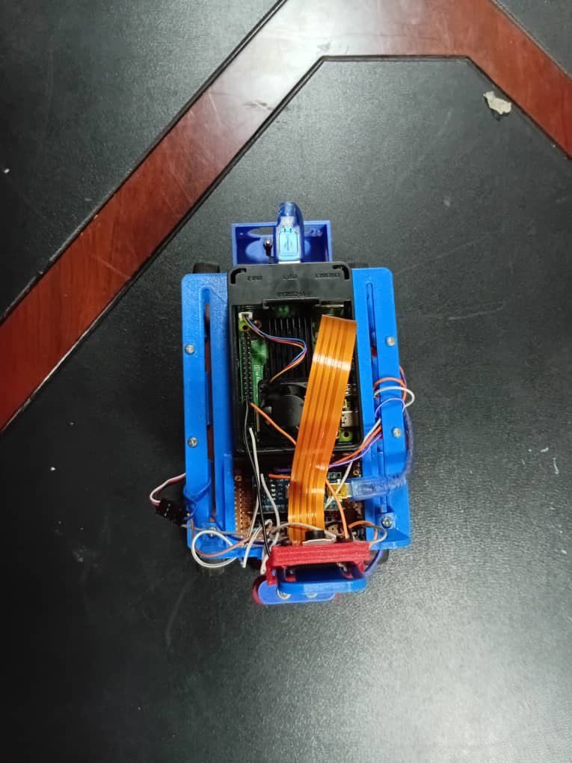
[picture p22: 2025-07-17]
v-photos/top.jpg

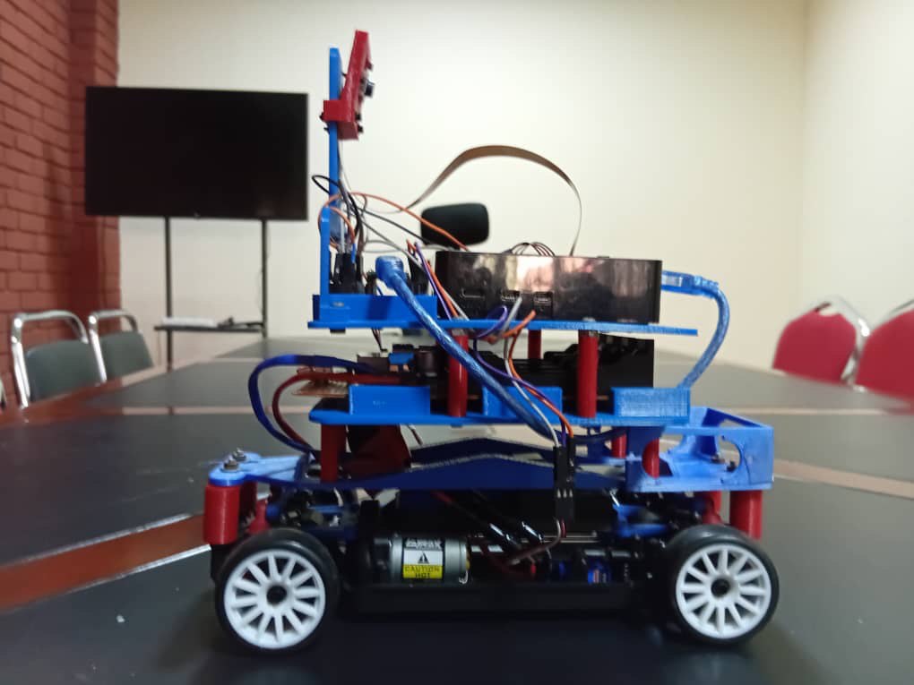
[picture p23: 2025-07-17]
v-photos/right.jpg

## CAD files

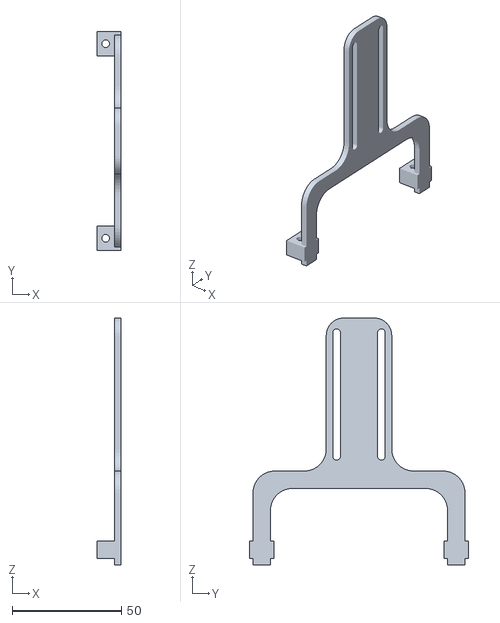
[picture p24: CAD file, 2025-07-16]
models/Assem1 - Camera Support frame-1.STL
11.0 x 100.0 x 113.0

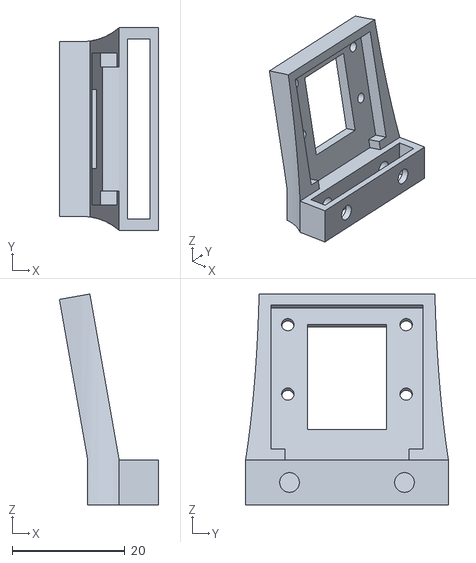
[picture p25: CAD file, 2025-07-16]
models/Assem1 - Camera mold-1.STL
17.6 x 36.0 x 37.4

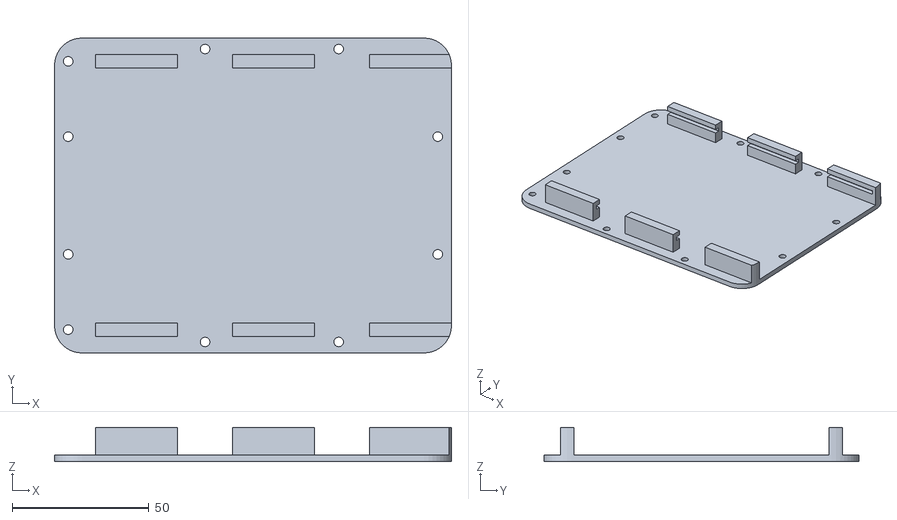
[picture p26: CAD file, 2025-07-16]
models/Assem1 - Power supply platform-1.STL
145.0 x 115.0 x 12.5

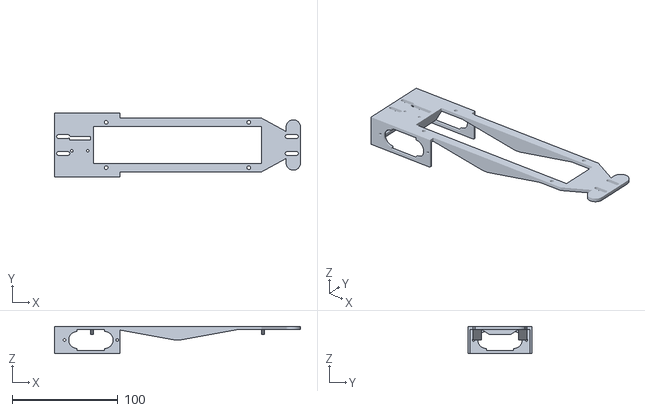
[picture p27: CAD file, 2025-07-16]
models/New support frame.STL
233.0 x 61.0 x 26.0

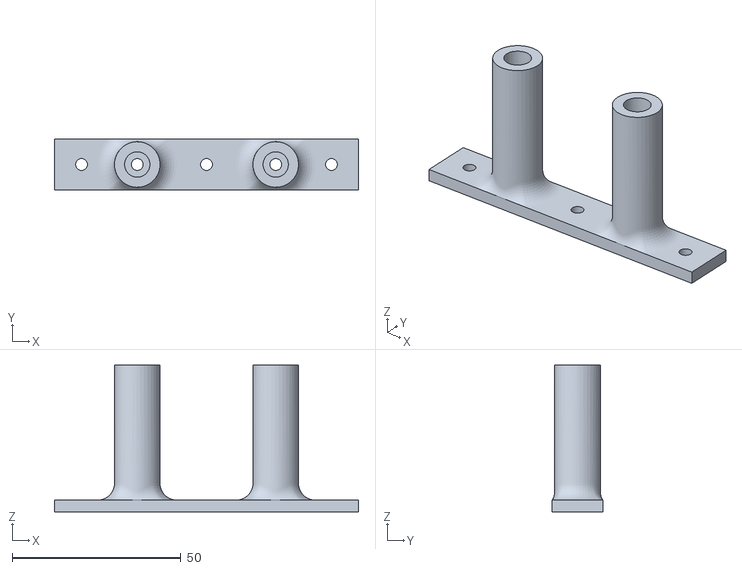
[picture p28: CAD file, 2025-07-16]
models/Mount.STL
90.0 x 15.0 x 43.5

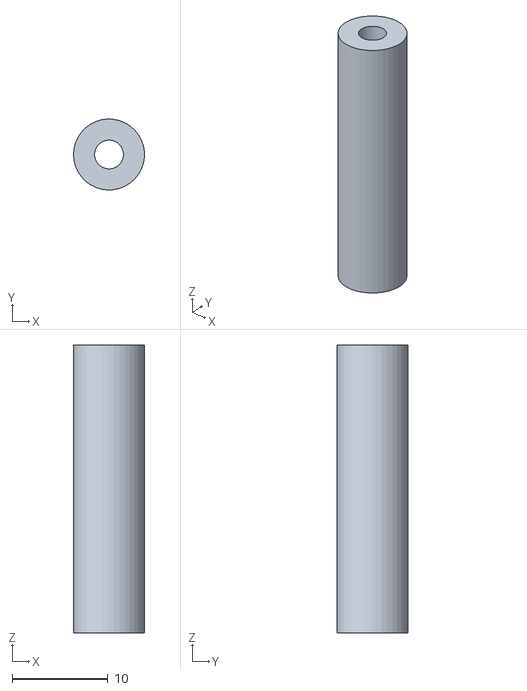
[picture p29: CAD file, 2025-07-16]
models/Assem1 - Lower Pillars-8.STL
7.40 x 7.39 x 30.0

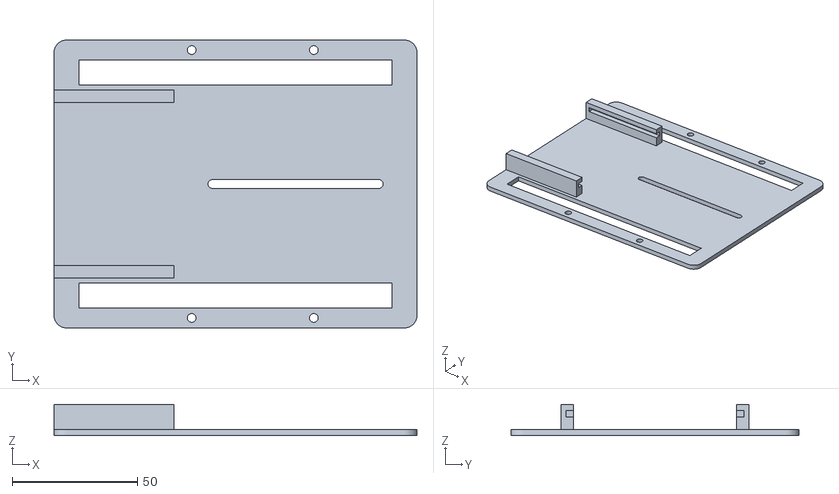
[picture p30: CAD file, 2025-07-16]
models/Assem1 - Top platform-1.STL
145.0 x 115.0 x 12.5

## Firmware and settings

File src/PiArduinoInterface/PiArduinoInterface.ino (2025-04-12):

#define USE_BASE      // Enable the base controller code
//#undef USE_BASE     // Disable the base controller code

/* Define the motor controller and encoder library you are using */
#ifdef USE_BASE
  #define ESC_DRIVER
#endif

#define USE_SERVOS  // Enable use of PWM servos as defined in servos.h
// #undef USE_SERVOS     // Disable use of PWM servos

/* Serial port baud rate */
#define BAUDRATE     9600


#if defined(ARDUINO) && ARDUINO >= 100
#include "Arduino.h"
#else
#include "WProgram.h"
#endif

/* Include definition of serial commands */
#include "commands.h"

/* Include servo support if required */
#ifdef USE_SERVOS
   #include <Servo.h>
   #include "servos.h"
#endif

#ifdef USE_BASE
  /* Motor driver function definitions */
  #include "motor_driver.h"

  #define AUTO_STOP_INTERVAL 2000
  long lastMotorCommand = AUTO_STOP_INTERVAL;
#endif


/* Variable initialization */

// A pair of varibles to help parse serial commands (thanks Fergs)
int arg = 0;
int index = 0;

// Variable to hold an input character
char chr;

// Variable to hold the current single-character command
char cmd;

// Character arrays to hold the first and second arguments
char argv1[16];
char argv2[16];

// The arguments converted to integers
long arg1;
long arg2;

/* Clear the current command parameters */
void resetCommand() {
  cmd = NULL;
  memset(argv1, 0, sizeof(argv1));
  memset(argv2, 0, sizeof(argv2));
  arg1 = 0;
  arg2 = 0;
  arg = 0;
  index = 0;
}

/* Run a command.  Commands are defined in commands.h */
int runCommand() {
  int i = 0;
  char *p = argv1;
  char *str;
  int pid_args[4];
  arg1 = atoi(argv1);
  arg2 = atoi(argv2);
  
  switch(cmd) {
  case GET_BAUDRATE:
    Serial.println(BAUDRATE);
    break;
  case ANALOG_READ:
    Serial.println(analogRead(arg1));
    break;
  case DIGITAL_READ:
    Serial.println(digitalRead(arg1));
    break;
  case ANALOG_WRITE:
    analogWrite(arg1, arg2);
    Serial.println("OK"); 
    break;
  case DIGITAL_WRITE:
    if (arg2 == 0) digitalWrite(arg1, LOW);
    else if (arg2 == 1) digitalWrite(arg1, HIGH);
    Serial.println("OK"); 
    break;
  case PIN_MODE:
    if (arg2 == 0) pinMode(arg1, INPUT);
    else if (arg2 == 1) pinMode(arg1, OUTPUT);
    Serial.println("OK");
    break;
#ifdef USE_SERVOS
  case SERVO_WRITE:
    servos[arg1].setTargetPosition(arg2);
    Serial.println("OK");
    break;
  case SERVO_READ:
    Serial.println(servos[arg1].getServo().read());
    break;
#endif
    
#ifdef USE_BASE
  // case MOTOR_SPEEDS:
  //   /* Reset the auto stop timer */
  //   lastMotorCommand = millis();
  //   if (arg1 == 0) {
  //     setMotorSpeeds(0);
  //   }
  //   Serial.println("OK"); 
  //   break;
  case MOTOR_RAW_PWM:
    /* Reset the auto stop timer */
    lastMotorCommand = millis();
    setMotorSpeeds(arg1);
    Serial.println("OK"); 
    break;
#endif
  default:
    Serial.println("Invalid Command");
    break;
  }
}

/* Setup function--runs once at startup. */
void setup() {
  Serial.begin(BAUDRATE);

// Initialize the motor controller if used */
#ifdef USE_BASE
  initMotorController();
#endif

/* Attach servos if used */
  #ifdef USE_SERVOS
    int i;
    for (i = 0; i < N_SERVOS; i++) {
      servos[i].initServo(
          servoPins[i],
          stepDelay[i],
          servoInitPosition[i]);
    }
  #endif
}

/* Enter the main loop.  Read and parse input from the serial port
   and run any valid commands. Run a PID calculation at the target
   interval and check for auto-stop conditions.
*/
void loop() {
  while (Serial.available() > 0) {
    
    // Read the next character
    chr = Serial.read();

    // Terminate a command with a CR
    if (chr == 13) {
      if (arg == 1) argv1[index] = NULL;
      else if (arg == 2) argv2[index] = NULL;
      runCommand();
      resetCommand();
    }
    // Use spaces to delimit parts of the command
    else if (chr == ' ') {
      // Step through the arguments
      if (arg == 0) arg = 1;
      else if (arg == 1)  {
        argv1[index] = NULL;
        arg = 2;
        index = 0;
      }
      continue;
    }
    else {
      if (arg == 0) {
        // The first arg is the single-letter command
        cmd = chr;
      }
      else if (arg == 1) {
        // Subsequent arguments can be more than one character
        argv1[index] = chr;
        index++;
      }
      else if (arg == 2) {
        argv2[index] = chr;
        index++;
      }
    }
  }
  
#ifdef USE_BASE  
  // Check to see if we have exceeded the auto-stop interval
  if ((millis() - lastMotorCommand) > AUTO_STOP_INTERVAL) {;
    setMotorSpeeds(0);
  }
#endif

// Sweep servos
#ifdef USE_SERVOS
  int i;
  for (i = 0; i < N_SERVOS; i++) {
    servos[i].doSweep();
  }
#endif
}

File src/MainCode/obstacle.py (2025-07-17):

import cv2
from picamera2 import Picamera2
from ArduinoComms import ArduinoComms
from pid import PIDController
import numpy as np
from masks import rOrange, rBlack, rBlue, rRed, rGreen
import time
from time import sleep
from utils import display_roi, display_variables, find_contours, max_contour

def main():
    time.sleep(3)

    picam2 = Picamera2()
    sensor_modes = picam2.sensor_modes
    selected_mode = None
    for mode in sensor_modes:
        if mode['size'] == (2304, 1296) or mode['size'] == (1920, 1080) or mode['size'] == (1280, 720):
            selected_mode = mode
            break
    if selected_mode is None:
        selected_mode = sensor_modes[0]

    config = picam2.create_preview_configuration(
        main={"format": "RGB888", "size": (1280, 720)},
        sensor={"output_size": selected_mode['size'], "bit_depth": selected_mode['bit_depth']}
    )

    picam2.configure(config)
    picam2.start()
    time.sleep(1)

    # Regions of interest
    ROI1 = [10, 420, 200, 500]  # left
    ROI2 = [1080, 420, 1270, 500]  # right
    ROI3 = [540, 420, 740, 500]  # center
    ROI_PILLAR = [340, 200, 940, 500]

    arduino = ArduinoComms()
    arduino.connect("/dev/serial/by-id/usb-1a86_USB2.0-Ser_-if00-port0", 9600, 1000)

    lTurn = False
    rTurn = False
    t = 0
    kp = 0.004#0.001
    kd = 0.0009
    pid = PIDController(kp, 0, kd)
    straightConst = 90
    turnThresh = 150
    exitThresh = 1500
    angle = 90
    prevAngle = angle
    tDeviation = 45
    sharpRight = straightConst - tDeviation
    sharpLeft = straightConst + tDeviation
    maxRight = straightConst - 60
    maxLeft = straightConst + 60
    speed = 190
    error = 0
    arduino.set_drive_motor_value(0)
    sleep(2)

    lDetected = False
    debug = True
    start = False
    turnDir = "none"
    last_turn_time = 0
    turn_cooldown = 1  # seconds cooldown after detecting a turn

    while True:
        rightArea, leftArea = 0, 0
        img = picam2.capture_array()
        img_lab = cv2.cvtColor(img, cv2.COLOR_BGR2Lab)
        img_lab = cv2.GaussianBlur(img_lab, (7, 7), 0)

        cListLeft = find_contours(img_lab, rBlack, ROI1)
        cListRight = find_contours(img_lab, rBlack, ROI2)
        cListOrange = find_contours(img_lab, rOrange, ROI3)
        cListBlue = find_contours(img_lab, rBlue, ROI3)

        cListRed = find_contours(img_lab, rRed, ROI_PILLAR)
        cListGreen = find_contours(img_lab, rGreen, ROI_PILLAR)

        leftArea = max_contour(cListLeft, ROI1)[0]
        rightArea = max_contour(cListRight, ROI2)[0]

        redArea = max_contour(cListRed, ROI_PILLAR)[0]
        greenArea = max_contour(cListGreen, ROI_PILLAR)[0]

        if max_contour(cListOrange, ROI3)[0] > 100:
            lDetected = True
            if turnDir == "none":
                turnDir = "right"
        elif max_contour(cListBlue, ROI3)[0] > 100:
            lDetected = True
            if turnDir == "none":
                turnDir = "left"

        cv2.drawContours(img[ROI3[1]:ROI3[3], ROI3[0]:ROI3[2]], cListOrange, -1, (0, 255, 0), 2)
        cv2.drawContours(img[ROI1[1]:ROI1[3], ROI1[0]:ROI1[2]], cListLeft, -1, (0, 255, 0), 2)
        cv2.drawContours(img[ROI2[1]:ROI2[3], ROI2[0]:ROI2[2]], cListRight, -1, (0, 255, 0), 2)
        cv2.drawContours(img[ROI_PILLAR[1]:ROI_PILLAR[3], ROI_PILLAR[0]:ROI_PILLAR[2]], cListRed, -1, (0, 0, 255), 2)
        cv2.drawContours(img[ROI_PILLAR[1]:ROI_PILLAR[3], ROI_PILLAR[0]:ROI_PILLAR[2]], cListGreen, -1, (0, 255, 0), 2)
        print(redArea, greenArea)
        if redArea > 3000 or greenArea > 900:
            arduino.set_drive_motor_value(speed)
            if redArea > 3000:  # Detected red pillar
                print("Red pillar detected — go RIGHT")
                angle = sharpRight  # steer right to go around it
                arduino.set_steering_motor_value(angle)
                sleep(0.25)  # briefly steer
                arduino.set_steering_motor_value(straightConst)  # straighten
            elif greenArea > 900:
                print("Green pillar detected — go LEFT")
                angle = sharpLeft  # steer left
                arduino.set_steering_motor_value(angle)
                sleep(0.25)
                arduino.set_steering_motor_value(straightConst)

        else:
            error = rightArea - leftArea
            angle = int(max(straightConst + pid.compute(error), 0))

            if leftArea <= turnThresh and not rTurn:
                lTurn = True
            elif rightArea <= turnThresh and not lTurn:
                rTurn = True

            if not start:
                arduino.set_steering_motor_value(90)
                arduino.set_drive_motor_value(speed)
                start = True

            arduino.set_drive_motor_value(speed)

            if angle != prevAngle:
                if lTurn or rTurn:
                    if (rightArea > exitThresh and rTurn) or (leftArea > exitThresh and lTurn):
                        lTurn = False
                        rTurn = False
                        pid.prev_error = 0
                        if lDetected:
                            current_time = time.time()
                            if current_time - last_turn_time > turn_cooldown:  # Check cooldown
                                t += 1
                                last_turn_time = current_time  # Update last turn time
                                lDetected = False

                    elif lTurn:
                        angle = min(max(angle, sharpLeft), maxLeft)
                    elif rTurn:
                        angle = max(min(angle, sharpRight), maxRight)

                    arduino.set_steering_motor_value(90)
                    time.sleep(0.05)
                    arduino.set_steering_motor_value(angle)
                    time.sleep(0.01)
                else:
                    arduino.set_steering_motor_value(max(min(angle, sharpLeft), sharpRight))
                    time.sleep(0.01)

        pid.prev_error = error
        prevAngle = angle

        if t == 12 and abs(angle - straightConst) <= 10:
            if turnDir == "left":
                sleep(1)
            else:
                sleep(1.5)

            arduino.set_drive_motor_value(0)
            break

        if debug:
            if cv2.waitKey(1) == ord('q'):
                arduino.set_drive_motor_value(0)
                break

            img = display_roi(img, [ROI1, ROI2, ROI3, ROI_PILLAR], (255, 204, 0))
            cv2.imshow("finalColor", img)

            variables = {
                "left wall area": leftArea,
                "right wall area": rightArea,
                "left turn": lTurn,
                "right turn": rTurn,
                "# turns": t,
                "lDetected": lDetected
            }

            display_variables(variables)

    if debug:
        cv2.destroyAllWindows()

if __name__ == "__main__":
    main()

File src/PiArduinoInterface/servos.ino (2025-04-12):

/***************************************************************
   Servo Sweep - by Nathaniel Gallinger

   Sweep servos one degree step at a time with a user defined
   delay in between steps.  Supports changing direction 
   mid-sweep.  Important for applications such as robotic arms
   where the stock servo speed is too fast for the strength
   of your system.

 *************************************************************/

 #ifdef USE_SERVOS


 // Constructor
 SweepServo::SweepServo()
 {
   this->currentPositionDegrees = 0;
   this->targetPositionDegrees = 0;
   this->lastSweepCommand = 0;
 }
 
 
 // Init
 void SweepServo::initServo(
     int servoPin,
     int stepDelayMs,
     int initPosition)
 {
   this->servo.attach(servoPin);
   this->stepDelayMs = stepDelayMs;
   this->currentPositionDegrees = initPosition;
   this->targetPositionDegrees = initPosition;
   this->lastSweepCommand = millis();
 }
 
 
 // Perform Sweep
 void SweepServo::doSweep()
 {
 
   // Get ellapsed time
   int delta = millis() - this->lastSweepCommand;
 
   // Check if time for a step
   if (delta > this->stepDelayMs) {
     // Check step direction
     if (this->targetPositionDegrees > this->currentPositionDegrees) {
       this->currentPositionDegrees++;
       this->servo.write(this->currentPositionDegrees);
     }
     else if (this->targetPositionDegrees < this->currentPositionDegrees) {
       this->currentPositionDegrees--;
       this->servo.write(this->currentPositionDegrees);
     }
     // if target == current position, do nothing
 
     // reset timer
     this->lastSweepCommand = millis();
   }
 }
 
 
 // Set a new target position
 void SweepServo::setTargetPosition(int position)
 {
   this->targetPositionDegrees = position;
 }
 
 
 // Accessor for servo object
 Servo SweepServo::getServo()
 {
   return this->servo;
 }
 
 
 #endif

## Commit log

2025-04-12 Implement functionality for interfacing between arduino and rasperry pi at the arduino side
2025-04-13 Implement communication from pi to arduino
2025-04-29 Adjust range for driving motor
2025-05-01 Change pinout for servo and driving motors
2025-05-05 Use serial by id for connection to arduino
2025-05-05 Increase steering range
2025-05-05 Invert steering
2025-07-07 Add files via upload
    The ultrasonic_reader.py holds the class definition for reading the ultrasonic sensors.
    The Ultrasonicopen.py is where I use the ultrasonic in the open challenge
2025-07-16 Add circuit diagram
2025-07-16 Add 3d models
    [Assem1 - Camera Support frame-1.STL, Assem1 - Camera mold-1.STL, Assem1 - Lower Pillars-8.STL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]
2025-07-16 Fix issue with jumper wires image
2025-07-17 Add script for getting program to wait for button press after booting
